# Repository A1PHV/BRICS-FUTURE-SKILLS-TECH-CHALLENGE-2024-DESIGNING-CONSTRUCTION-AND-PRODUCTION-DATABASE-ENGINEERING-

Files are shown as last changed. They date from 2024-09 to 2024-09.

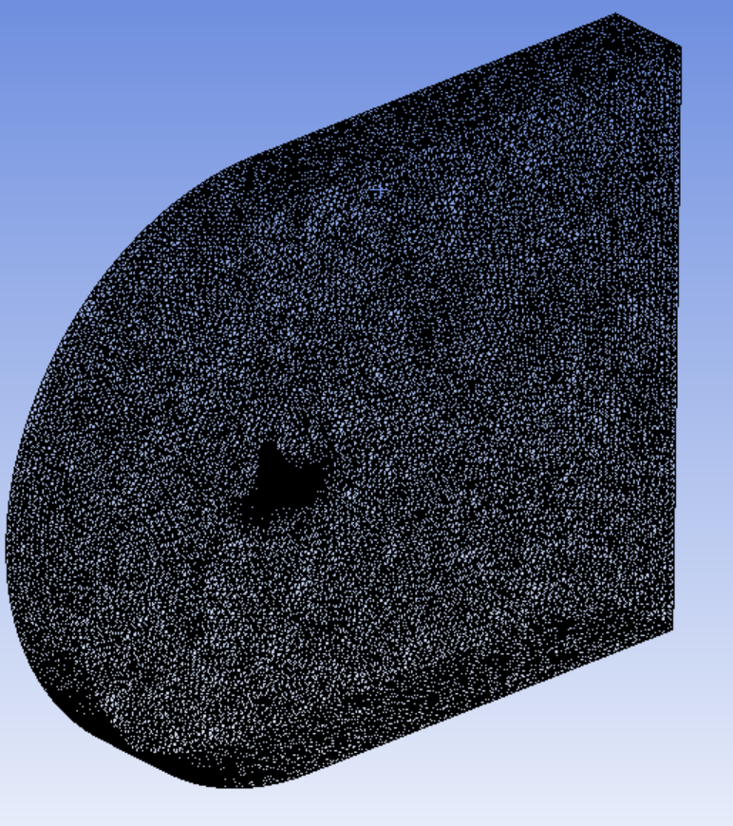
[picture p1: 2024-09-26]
Результаты расчета/Ansys/Сетка.png

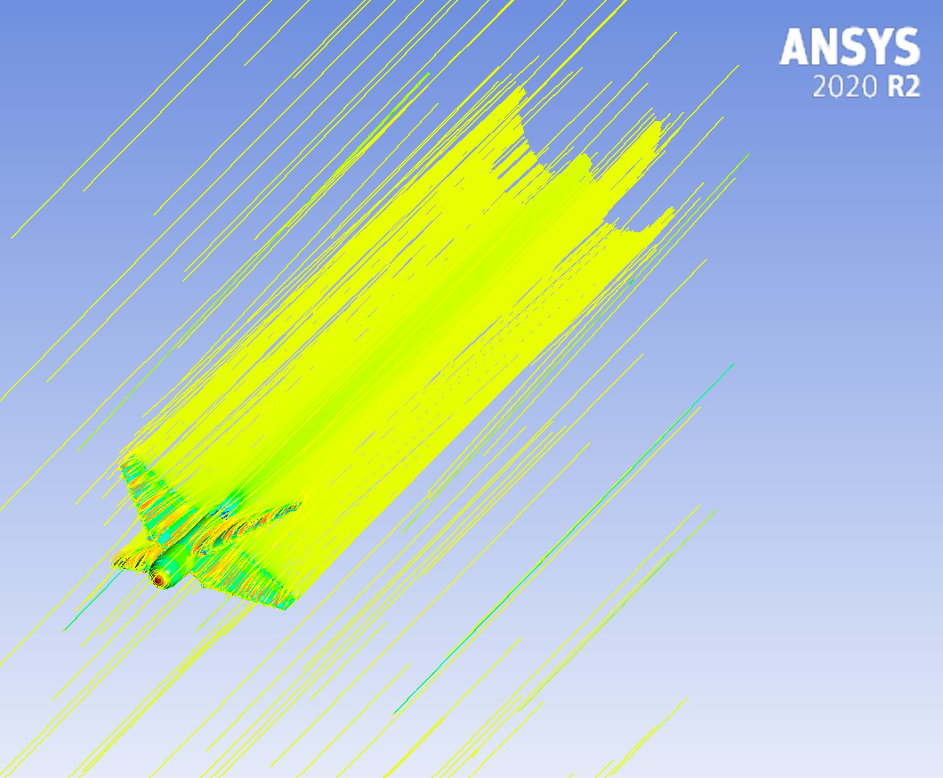
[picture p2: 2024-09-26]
Результаты расчета/Ansys/Альфа_3_1.png

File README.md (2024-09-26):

# BRICS-FUTURE-SKILLS-TECH-CHALLENGE-2024-ПРОЕКТИРОВАНИЕ-КОНСТРУИРОВАНИЕ-И-ПРОИЗВОДСТВЕННАЯ-ИНЖЕНЕРИЯ-БАС
### Название проекта:
  Sagittarius
### Цель:
  Создать проект малого БПЛА для доставки медикаментов в труднодоступные и отдалённые места.
### Основные функции и преимущества системы: 
  - Оперативная доставка необходимого оборудования и материалов к месту чрезвычайной ситуации (до 30 минут)
  - Возможность оснащения различной целевой нагрузкой в зависимости от задачи
  - Низкая стоимость изготовления, сборки, обслуживания
  - Простота обслуживания и применения
  - Снижение углеродного следа и повышенная экологичность
  - Возможность применения в местности с отсутствием инфраструктуры 
  - Ниша с малой конкуренцией на рынке БПЛА
  - Высокий уровень автоматизации системы 
### Описание:
  Беспилотные летательные аппараты (БПЛА) становятся всё более популярными благодаря простоте их изготовления, лёгкости в обслуживании и способности к оперативной доставке оборудования в труднодоступные зоны за считанные минуты. Они значительно уменьшают воздействие на ресурсы планеты, потребляя меньше топлива, что делает их более экологически чистым решением в сравнении с классическими ЛА. БПЛА особенно полезны в труднодоступных местах, где отсутствует инфраструктура. Небольшая конкурентность на рынке предоставляет возможности для новых компаний и инновационных решений. Гибкость в конфигурации целевой нагрузки позволяет использовать БПЛА для различных задач, включая доставку медикаментов, мониторинг экологии, исследование местности и множество других задач. Эти преимущества превращают БПЛА в универсальные инструменты, способные эффективно реагировать на современные вызовы. Основная задача, которую решает наш проект, это проблема доставки медикаментов в труднодоступные места, где отсутствует явная инфраструктура, за кратчайшие сроки.
| ФИО Участника | Роль | Обязанности |
|---|---|---|
| Макаров Леонид Алексеевич | Капитан | Выстраивание рабочего процесса в команде, контроль выполнения задач |
| Лукьянова София Дмитриевна | Конструктор | Моделирование изготавливаемой модели, составление чертежей |
| Ефремов Александр Владимирович | Технолог | Разработка процесса производства, сборки и эксплуатации изделия |
| Жеков Александр Романович | Проектировщик  | Выбор аэродинамической компоновки, расчет проекта |
| Коротков Сергей Сергеевич | Программист | Модернизация программного обеспечения |
### Таблица:
[Таблица](https://docs.google.com/spreadsheets/d/11EvWEyuFIVLWnHRkrs40eNkXgBEI7as9F1RAO528Gh0/edit?gid=0#gid=0)
### Требования к системе:
  - Обеспечить доставку грузов в радиусе 15 км;
  - Обеспечить потребного времени полета (30 мин.);
  - Обеспечить эксплуатацию на площадках с минимальной подготовкой;
  - Обеспечить доставку груза (приземления) на неподготовленные площадки;
  - Обеспечить эксплуатацию оператором с минимальным образованием;
  - Автономный полет.

## Проектирование
Результаты расчетов и 3д модель в различных форматах приложены в репозитории.
Фото летных испытаний можно найти в репозитории, а также по [ссылке на яндекс диске](https://disk.yandex.ru/d/UMUnpoecSOcVCQ).

## Итоговый отчёт представлен в различных форматах в корневой папке.

## Презентация
Доступна [по ссылке на ЯД](https://disk.yandex.ru/d/4SBGewQKKxqp1A) из-за большого объема.

# BRICS-FUTURE-SKILLS-TECH-CHALLENGE-2024-DESIGNING-CONSTRUCTION-AND-PRODUCTION-DATABASE-ENGINEERING
### Project name:
  Sagittarius
### Goal:
  To create a small UAV project for delivering medical supplies to hard-to-reach and remote areas.
  
### Key features and system advantages:
  - Rapid delivery of essential equipment and materials to emergency locations (within 30 minutes)
  - Ability to equip with various payloads depending on the task
  - Low cost of production, assembly, and maintenance
  - Easy to maintain and operate
  - Reduced carbon footprint and increased eco-friendliness
  - Usable in areas with no infrastructure
  - Low competition niche in the UAV market
  - High level of system automation
  
### Description:
  Unmanned aerial vehicles (UAVs) are becoming increasingly popular due to their ease of manufacturing, low maintenance, and ability to quickly deliver equipment to remote locations within minutes. They significantly reduce the strain on planetary resources, consuming less fuel, which makes them a more environmentally friendly solution compared to traditional aircraft. UAVs are especially useful in remote areas where infrastructure is lacking. Low competition in the market offers opportunities for new companies and innovative solutions. The flexibility in configuring the payload allows UAVs to be used for various tasks, including medical deliveries, environmental monitoring, terrain exploration, and many other applications. These advantages make UAVs versatile tools capable of effectively responding to modern challenges. The main task our project addresses is the problem of delivering medical supplies to remote areas lacking clear infrastructure in the shortest possible time.
| Participant's Name | Role | Responsibilities |
|---|---|---|
| Makarov Leonid Alekseevich | Captain | Organizing the team’s workflow, monitoring task completion |
| Lukyanova Sofia Dmitrievna | Constructor | Modeling the product, drafting the technical drawings |
| Efremov Alexander Vladimirovich | Technologist | Developing the production process, assembly, and product operation |
| Zhekov Alexander Romanovich | Designer | Selecting the aerodynamic configuration, project calculations |
| Korotkov Sergey Sergeevich | Programmer | Software modernization |
### Table:
[Тable](https://docs.google.com/spreadsheets/d/11EvWEyuFIVLWnHRkrs40eNkXgBEI7as9F1RAO528Gh0/edit?gid=0#gid=0)
### System requirements:
  - Ensure the delivery of goods within a radius of 15 km;
  - To ensure the required flight time (30 minutes);
  - To ensure operation on sites with minimal preparation;
  - To ensure the delivery of cargo (landing) to unprepared sites;
  - Ensure operation by an operator with minimal education;
  - Autonomous flight.

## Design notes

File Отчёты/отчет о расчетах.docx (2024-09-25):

Описание этапов проектирования

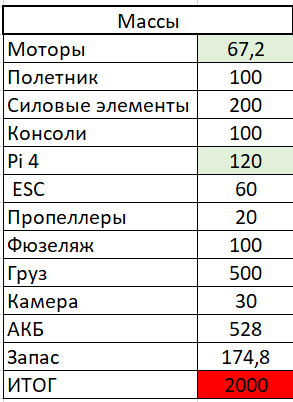
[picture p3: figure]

1. Анализ рынка
2. Создание весовой сводки

Исходя из представленных требований и наборы необходимых компонентов масса ЛА была выбрана 2кг, далее составлена весовая сводка по агрегатам и элементам.

3. Расчет винто-моторной группы

Для того, чтобы иметь точное представление о том, какой нужен аккумулятор и двигатель, проведём несколько расчётов. Первым делом выведем формулу, с помощью которой сможем посчитать ёмкость АКБ для маршевого и подъёмных двигателей.

E=P/U⋅1/η⋅t⋅(1+Q)⋅ke⋅kc

Где: E – ёмкость АКБ в Ампер*час;

P – крейсерская мощность двигателя(ей) в Ваттах;

U – напряжение АКБ в Вольтах;

η – КПД мотора(ов);

t – время полёта в Часах;

Q – аэронавигационный запас;

ke – коэффициент, учитывающий просадку напряжения при малой остаточной емкости;

kc – коэффициент, учитывающий зависимость располагаемой емкости от скорости разряда.

Итог расчета:

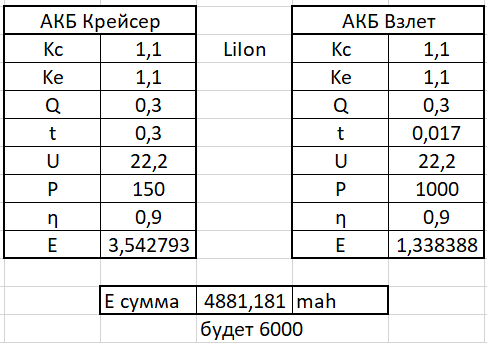
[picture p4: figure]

4. Расчет проектных параметров

Крейсерская скорость бралась исходя из анализа дальности и потребления двигателя.

- Взлетная масса - 2 кг;
- Крейсерская скорость - 108 км/ч (30 м/c);
- Плотность воздуха на высоте 100м - 1,213 кг/м3;

Расчет скоростного напора

В исходных данных мы имеем все необходимые значения для расчета скоростного напора по формуле:

Получено значение q=546 [кг/(м*с)^2].

Удельная нагрузка на крыло

Су крейс. = 0,4 – коэффициент подъемной силы, взятый из программы OpenVSP для модели аппарата в нулевом приближении;

Удельную нагрузку было решено взять исходя из опыта в проектировании малых ЛА. Получено значение p``=65 [кгс/м^2];

Размеры крыла

Имея удельную нагрузку на крыло, можем вычислить потребную площадь крыла по формуле:

(1)

Где:

m0 – масса в первом приближении [кг];

p``0 – удельная нагрузка на крыло. Получаем S=0,307 [м^2];

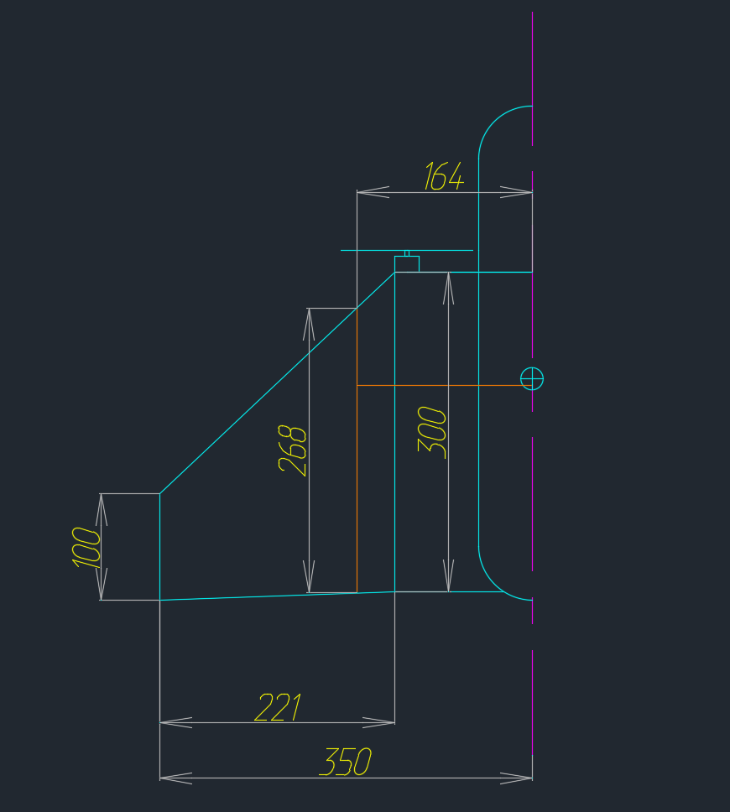
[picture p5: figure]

5. Расчет геометрических параметров

Геометрические параметры ЛА в программе AutoCad

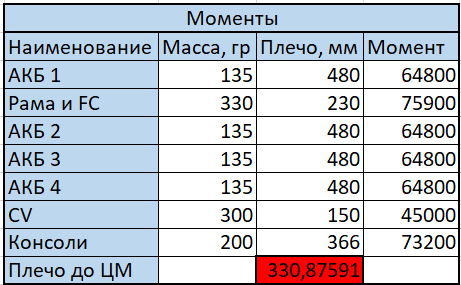
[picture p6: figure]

6. Создание центровочной ведомости

Центровочная ведомость

7. Анализ аэродинамических параметров

Перед тем как выбрать профиль крыла, необходимо оценить параметры среды на заданном режиме полета – расчет числа Рейнольдса на крейсерской скорости:

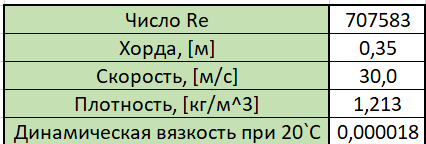
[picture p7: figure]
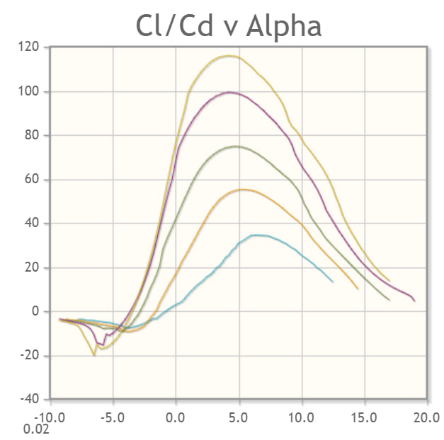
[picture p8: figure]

В качестве аэродинамического профиля крыла выбран профиль sd7037-il так как он хорошо оптимизирован под эксплуатационный диапазон чисел Рейнольдса нашего ЛА. Характеристики профиля были оценены в специализированной программе XFLR5 и получены следующие зависимости

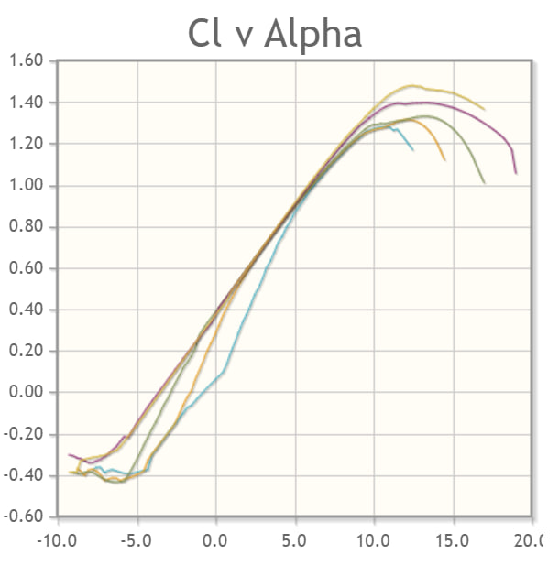
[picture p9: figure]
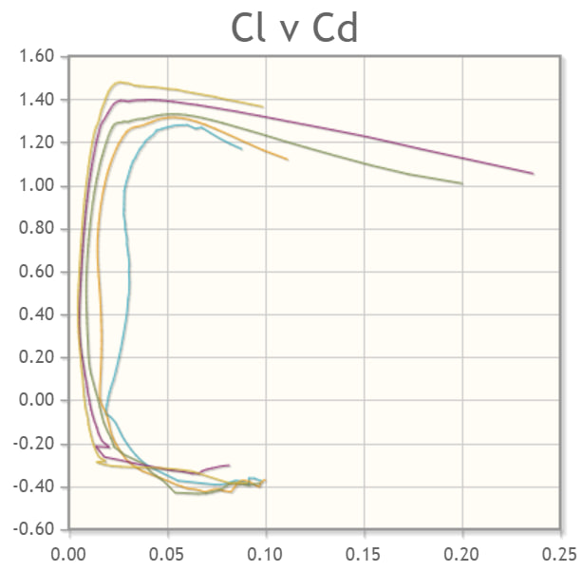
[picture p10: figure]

На графиках представлены зависимости аэродинамического качества от угла атаки, коэффициента подъемной силы от угла атаки и коэффициената подъемной силы от коэффициента лобового сопротивления соответственно.

Далее представлена расчетная модель крыла изделия в XFLR5.

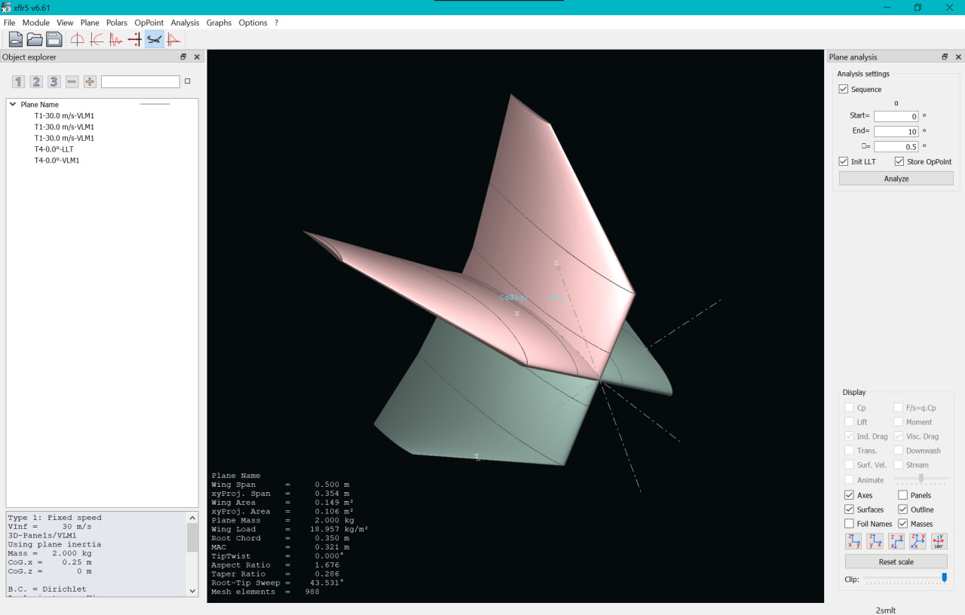
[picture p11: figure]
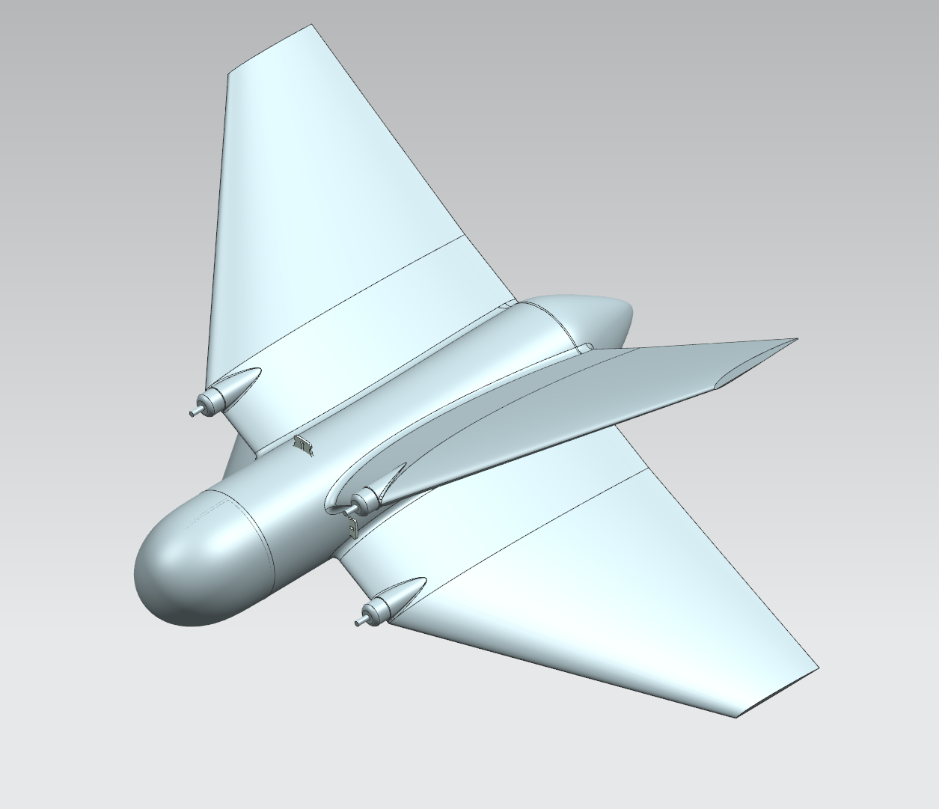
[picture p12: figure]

8. Создание электронного макета изделия

Электронный макет ЛА, созданый в программе Siemens NX.

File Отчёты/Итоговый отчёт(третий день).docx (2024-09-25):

Содержание:

# Оглавление

# 1. Перечень сокращений и терминов

- АК – авиационный комплекс;
- НПУ – наземный пункт управления;
- ЛА – летательный аппарат;
- БПЛА – беспилотный ЛА;

# 2. Описание проекта

## Цель проекта

Цель проекта заключается в разработке компактного беспилотного летательного аппарата, способного эффективно доставлять медикаменты в труднодоступные и отдаленные регионы. Данный БПЛА позволит значительно сократить время доставки жизненно важных лекарств в экстренных ситуациях и в условиях ограниченного доступа. Кроме того, проект направлен на улучшение доступности медицинских услуг для жителей удаленных территорий, обеспечивая их необходимыми препаратами и материалами.

## Преимущества БПЛА

Беспилотные летательные аппараты (БПЛА) становятся всё более популярными благодаря своим многочисленным преимуществам, которые делают их незаменимыми в различных сферах деятельности. Одним из самых значимых плюсов является лёгкость в обслуживании. Современные БПЛА разработаны с учётом простоты эксплуатации, что позволяет сократить время на обучение операторов и минимизировать затраты на техническое обслуживание. Кроме того, использование БПЛА способствует уменьшению воздействия на ресурсы планеты. Они потребляют значительно меньше топлива по сравнению с традиционными транспортными средствами, что делает их экологически чистым решением.

Одной из ключевых функций БПЛА является их способность к оперативной доставке необходимого оборудования в зоны чрезвычайных ситуаций, что крайне важно в случаях, когда каждая секунда на счету.

В настоящее время рынок БПЛА обладает небольшой конкурентностью, что предоставляет возможности для новых игроков и инновационных решений. Это создает простор для творческого подхода и внедрения оригинальных технологий.

Также, БПЛА предлагают возможность использования различных конфигураций целевой нагрузки, что расширяет их сферу применения. Это может быть как доставка медикаментов и продовольствия, так и мониторинг экологической ситуации или проведение инспекций инфраструктуры. Гибкость в настройках БПЛА обеспечивает их универсальность и возможность адаптации под конкретные задачи.

Таким образом, беспилотные летательные аппараты представляют собой многофункциональное и эффективное решение для сегодняшних вызовов, сочетая лёгкость в обслуживании, низкое воздействие на окружающую среду, быстрое реагирование на чрезвычайные ситуации, а также широкий спектр применения.

# 3. Анализ рынка

## Сравнение методов грузоперевозки

Грузоперевозка на различных видах транспорта имеет свои недостатки. Вот несколько из них:

1. Автомобильный транспорт:

- Зависимость от дорожной инфраструктуры: Качество дорог и наличие пробок могут значительно увеличить время доставки.

- Необходимость в дозаправки во время пути.

- Высокий уровень выбросов CO2 и загрязнение окружающей среды.

2. Железнодорожный транспорт:

- Неподвижность маршрутов: Поезда следуют строго определенным маршрутам, что может ограничить гибкость доставки и потребовать дополнительных затрат на подвозку грузов к станции.

- Ограниченная скорость: Средняя скорость 10 км/ч, также процессы погрузки и разгрузки требуют времени.

- Аварийные ситуации: Возможные задержки из-за технических неполадок или серьезных инцидентов на путях.

3. Крупный авиационный транспорт:

- Высокая стоимость: Доставка грузов по воздуху значительно дороже, чем другими видами транспорта, что делает ее менее доступной.

- Зависимость от инфраструктуры: отсутствие взлётно-посадочных полос, ангаров и квалифицированного персонала.

- Чувствительность к погодным условиям: Неблагоприятные погодные условия могут вызывать задержки и отмены рейсов.

4. Речной транспорт:

- Долгое время доставки: Перевозка грузов занимает много времени, что может быть критично для срочных грузов.

- Зависимость от портовой инфраструктуры: Задержки в портах из-за плохих погодных условий или перегрузки могут значительно увеличить общее время доставки.

- Риски повреждения грузов: Грузы могут подвергаться воздействию влаги, соли и других факторов, что может приводить к их повреждению.

Таблица 1 -  Сравнение методов перевозок.

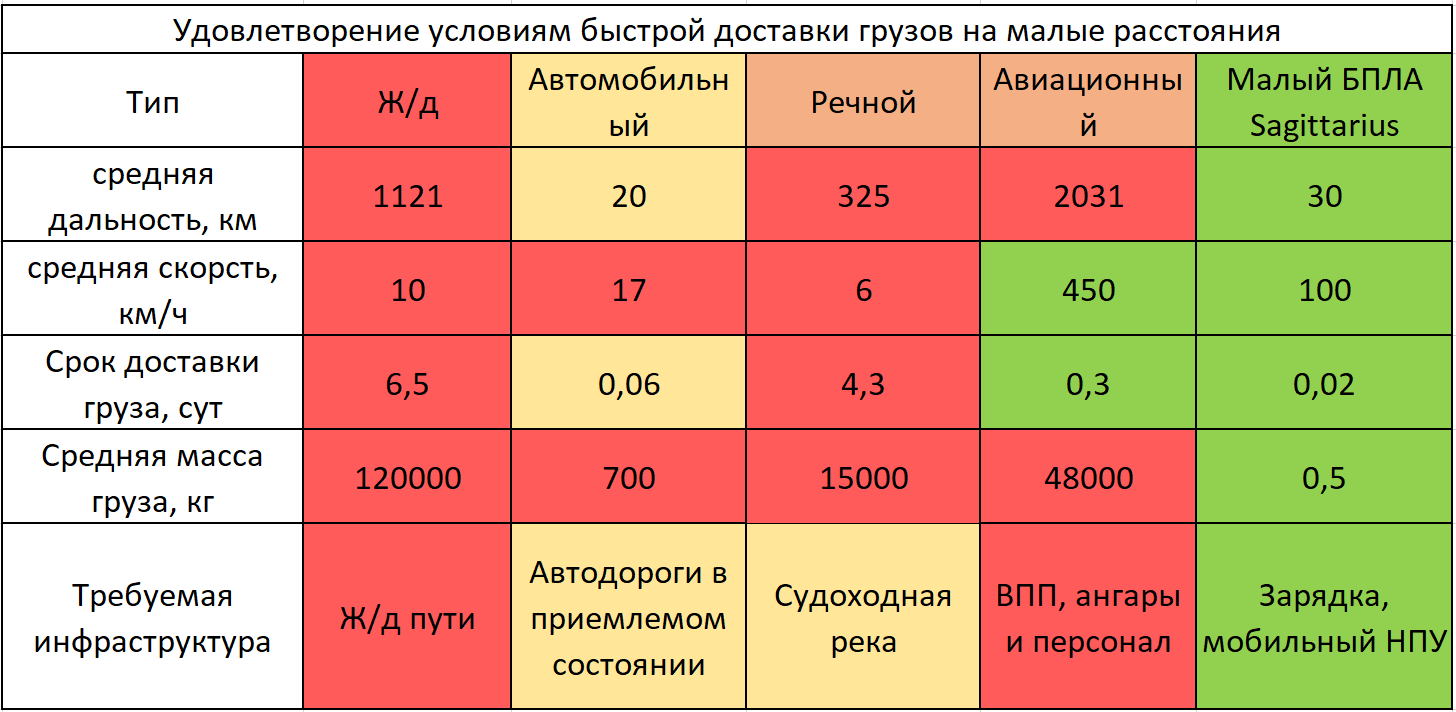
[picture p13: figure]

В настоящее время при доставки малогабаритных и срочных грузов, мы сталкиваемся с такими основными проблемами как, скорость доставки или нецелесообразность запуска крупного транспорта.

## Сравнение прототипов

Таблица 2 -  Сравнение прототипов.

Проанализировав рынок, мы пришли к выводу, что существующие авиационные прототипы нецелесообразно отправлять на небольшие расстояния для доставки медикаментов экстренной помощи. Обслуживание крупного авиационного транспорта является очень дорогим, а также в отдаленных регионах тяжело осуществить посадку, по причине малоразвитой инфраструктуры. В связи с этим нами было принято решение разработать БПЛА с дальностью полёта 30 км, крейсерской скоростью до 100 км/ч и возможностью вертикального взлета и посадки. Наш проект не только заполнит имеющийся рыночный пробел, но и сделает значительный вклад в развитие здравоохранения и экстренной помощи в удаленных регионах.

# 4. Список требований к системе

Требования к системе:

1. Дальность доставки: БПЛА должен иметь возможность совершать полеты на расстоянии до 15 км от стартовой площадки.
2. Время полета: БПЛА должен быть способен поддерживать полет не менее 30 минут, чтобы обеспечить выполнение задачи по доставке груза с учетом потенциальных задержек, отклонений от маршрута и времени на маневрирование при посадке.
3. Подготовка площадок: Обеспечение обслуживание на площадках с минимальной подготовкой.
4. Приземление на неподготовленных площадках: Обеспечение доставки груза (приземления) на неподготовленные площадки. Возможность точно и безопасно приземляться на поверхности с различными типами покрытия (травяные, земляные, бетонные и т.д.), что требует наличия системы автоматического управления и стабилизации во время приземления.
5. Обеспечение эксплуатации оператором с минимальным образованием: Система управления БПЛА должна быть интуитивно понятной, с простым интерфейсом и минимальными требованиями к обучению. Оператор должен иметь возможность быстро освоить управление БПЛА, возможно, с помощью инструкций на экране и простых команд.
6. Автономный полет: БПЛА должен быть оснащен системой автопилота, позволяющей ему совершать полет без непосредственного управления со стороны оператора. Это включает в себя заранее загруженные маршруты, возможность изменения маршрута в режиме реального времени и возможность возврата на базу в случае возникновения непредвиденных обстоятельств (например, разряд батареи, потеря сигнала).

Эти требования помогут обеспечить эффективную и безопасную эксплуатацию системы малого БПЛА для доставки грузов в различных условиях.

# 5. Расчеты ЛА

## Расчет массовых характеристик

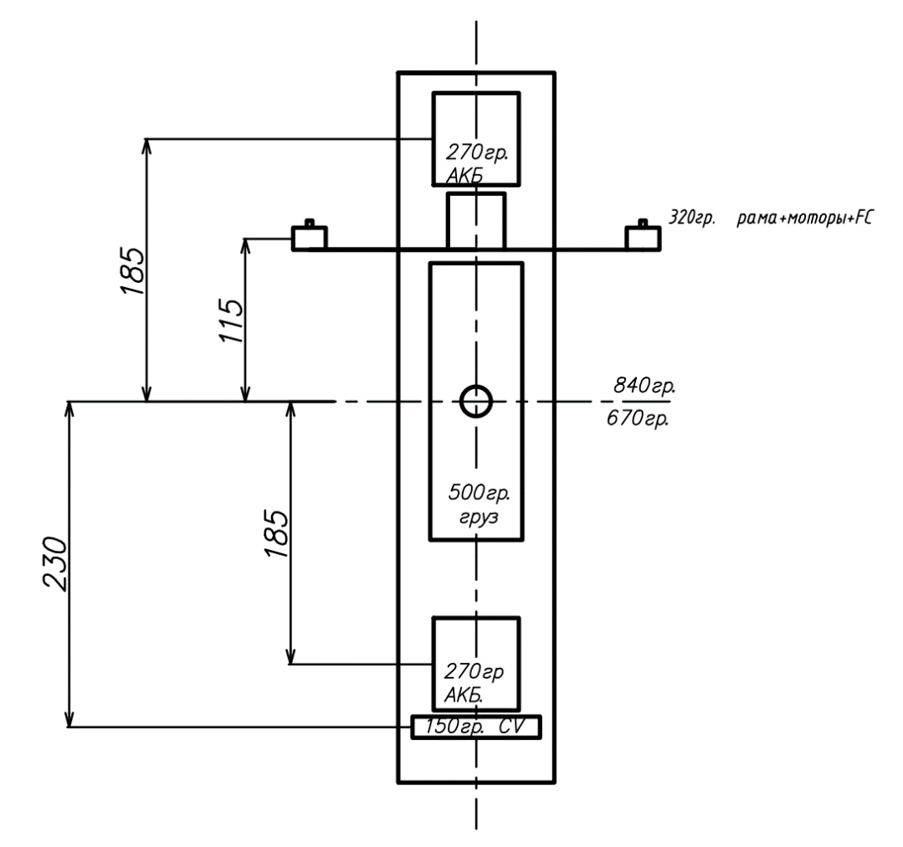
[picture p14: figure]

Рис. 1. -  Центровочная схема.

## Расчеты проектных параметров

## Расчет геометрических характеристик ЛА

## Расчет аэродинамических характеристик ЛА

## Расчет ВМГ

# 6. Построение электронного макета

# 7. Изготовление технологической оснастки

# 8. Описание АК

## Состав АК и причастных людей

В состав авиационного комплекса Sagittarius:

- Оператор

Выполняет обсуживание и загрузку полезной нагрузки в БПЛА на базе, настраивает и запускает миссию на доставку, а также контролирует ход её выполнения, имеет связь с каналом экстренных служб для получения информации о необходимости доставки.

- НПУ

Обеспечивает связь между оператором и роем БПЛА, управление роем.

- БПЛА (предполагается размещение нескольких единиц на одной базе)

Заряжается от НПУ, груз загружается вручную оператором, получает миссию от НПУ и автономно летит в точку назначения.

С АК взаимодействуют:

- Оператор экстренных служб (ОЭС) – передает данные о необходимости доставки, состав запрапрашиваемой доставки и точку назначения;
- Получатель – пострадавший или иной человек, кому потребовалась срочная доставка посылки от экстренных служб. Сообщает ОЭС свое местоположение и описывает ситуацию, извлекает груз из БПЛА в точке приземления.

## Взаимодействие элементов АК

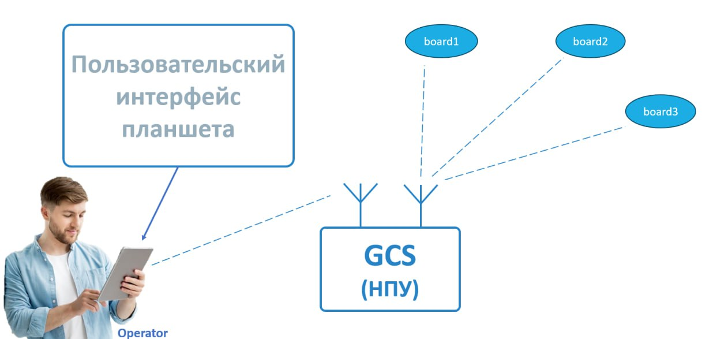
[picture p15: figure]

Рис. 2. -  Схема работы оператора

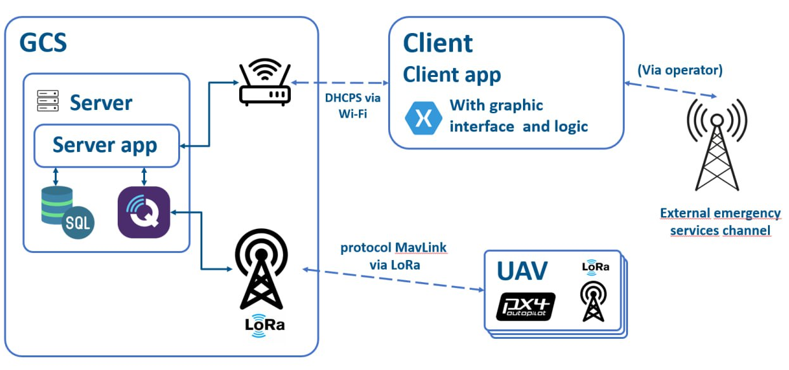
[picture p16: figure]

Рис. 3. -  Схема архитектуры взаимодействия

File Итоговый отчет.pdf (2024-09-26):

ОКБ СУХОГО
БПЛА Sagittarius

### Оглавление

2

### 7.1. Общий вид изделия | 20

### 7.2. Эксплуатационное членение | 23

### 8. Технологическая документация | 25

### 8.1. Технология изготовления БПЛА | 25

### 8.2. Описание технологического процесса сборки | 26

### 9. Расчёт экономической модели проекта | 1

3

### 1. Перечень сокращений и терминов

- АК – авиационный комплекс;
- НПУ – наземный пункт управления;
- ЛА – летательный аппарат;
- БПЛА – беспилотный ЛА;
- АДХ – Аэродинамические характеристики
- ОЭС

4

### 2. Описание проекта

### 2.1. Цель проекта

Цель проекта заключается в разработке компактного беспилотного летательного аппарата, способного эффективно доставлять медикаменты в труднодоступные и отдаленные регионы. Данный БПЛА позволит значительно сократить время доставки жизненно важных лекарств в экстренных ситуациях и в условиях ограниченного доступа. Кроме того, проект направлен на улучшение доступности медицинских услуг для жителей удаленных территорий, обеспечивая их необходимыми препаратами и материалами.

### 2.2. Преимущества БПЛА

Беспилотные летательные аппараты (БПЛА) становятся всё более популярными благодаря своим многочисленным преимуществам, которые делают их незаменимыми в различных сферах деятельности. Одним из самых значимых плюсов является лёгкость в обслуживании. Современные БПЛА разработаны с учётом простоты эксплуатации, что позволяет сократить время на обучение операторов и минимизировать затраты на техническое обслуживание. Кроме того, использование БПЛА способствует уменьшению воздействия на ресурсы планеты. Они потребляют значительно меньше топлива по сравнению с традиционными транспортными средствами, что делает их экологически чистым решением.
Одной из ключевых функций БПЛА является их способность к оперативной доставке необходимого оборудования в зоны чрезвычайных ситуаций, что крайне важно в случаях, когда каждая секунда на счету.
В настоящее время рынок БПЛА обладает небольшой конкурентностью, что предоставляет возможности для новых игроков и инновационных

5

решений. Это создает простор для творческого подхода и внедрения оригинальных технологий.
Также, БПЛА предлагают возможность использования различных конфигураций целевой нагрузки, что расширяет их сферу применения. Это может быть, как доставка медикаментов и продовольствия, так и мониторинг экологической ситуации или проведение инспекций инфраструктуры. Гибкость в настройках БПЛА обеспечивает их универсальность и возможность адаптации под конкретные задачи.
Таким образом, беспилотные летательные аппараты представляют собой многофункциональное и эффективное решение для сегодняшних вызовов, сочетая лёгкость в обслуживании, низкое воздействие на окружающую среду, быстрое реагирование на чрезвычайные ситуации, а также широкий спектр применения.

6

### 3. Анализ рынка

### 3.1. Сравнение методов грузоперевозки

Грузоперевозка на различных видах транспорта имеет свои недостатки. Вот несколько из них:

### 1. Автомобильный транспорт:

- Зависимость от дорожной инфраструктуры: Качество дорог и наличие пробок могут значительно увеличить время доставки.
- Необходимость в дозаправки во время пути.
- Высокий уровень выбросов CO2 и загрязнение окружающей среды.

### 2. Железнодорожный транспорт:

- Неподвижность маршрутов: Поезда следуют строго определенным маршрутам, что может ограничить гибкость доставки и потребовать дополнительных затрат на подвозку грузов к станции.
- Ограниченная скорость: Средняя скорость 10 км/ч, также процессы погрузки и разгрузки требуют времени.
- Аварийные ситуации: Возможные задержки из-за технических неполадок или серьезных инцидентов на путях.

### 3. Крупный авиационный транспорт:

- Высокая стоимость: Доставка грузов по воздуху значительно дороже, чем другими видами транспорта, что делает ее менее доступной.
- Зависимость от инфраструктуры: отсутствие взлётно-посадочных полос, ангаров и квалифицированного персонала.
- Чувствительность к погодным условиям: Неблагоприятные погодные условия могут вызывать задержки и отмены рейсов.

### 4. Речной транспорт:

- Долгое время доставки: Перевозка грузов занимает много времени, что может быть критично для срочных грузов.

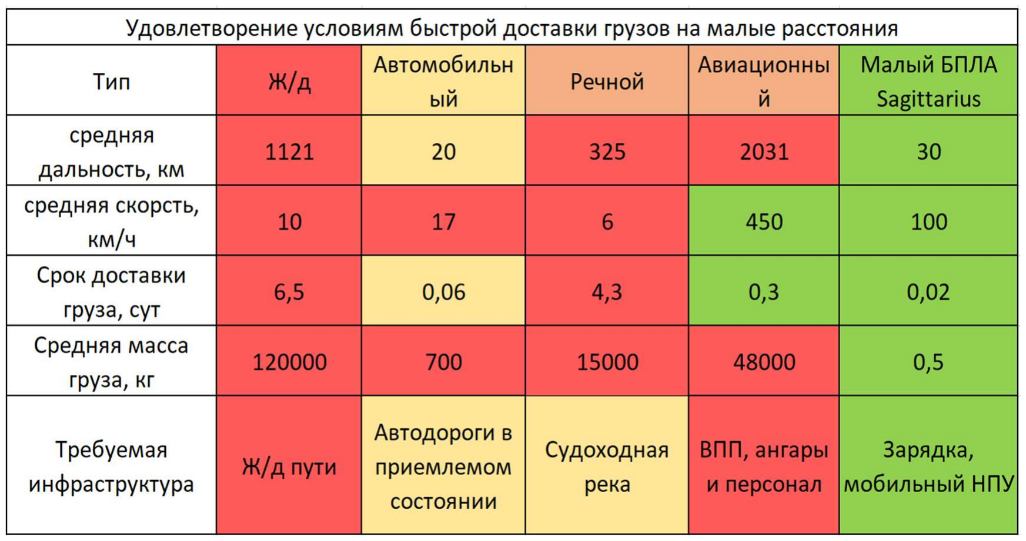
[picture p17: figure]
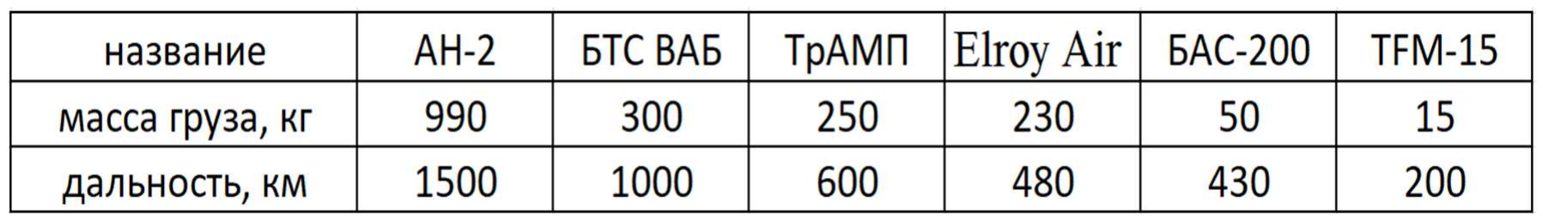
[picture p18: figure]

7

- Зависимость от портовой инфраструктуры: Задержки в портах из-за плохих погодных условий или перегрузки могут значительно увеличить общее время доставки.
- Риски повреждения грузов: Грузы могут подвергаться воздействию влаги, соли и других факторов, что может приводить к их повреждению. Таблица 1 - Сравнение методов перевозок.

В настоящее время при доставки малогабаритных и срочных грузов, мы сталкиваемся с такими основными проблемами как, скорость доставки или нецелесообразность запуска крупного транспорта.

### 3.2. Сравнение прототипов

Таблица 2 - Сравнение прототипов.

8

Проанализировав рынок, мы пришли к выводу, что существующие авиационные прототипы нецелесообразно отправлять на небольшие расстояния для доставки медикаментов экстренной помощи. Обслуживание крупного авиационного транспорта является очень дорогим, а также в отдаленных регионах тяжело осуществить посадку, по причине малоразвитой инфраструктуры. В связи с этим нами было принято решение разработать БПЛА с дальностью полёта 30 км, крейсерской скоростью до 100 км/ч и возможностью вертикального взлета и посадки. Наш проект не только заполнит имеющийся рыночный пробел, но и сделает значительный вклад в развитие здравоохранения и экстренной помощи в удаленных регионах.

0

200

400

600

800

1000

1200

1400

1600

1800

0 | 200 | 400 | 600 | 800 | 1000 | 1200 Дальность полета, км

Масса груза, кг

Зависимость массы груза от дальности полета

9

### 4. Список требований к системе

### 1. Дальность доставки: БПЛА должен иметь возможность совершать

полеты на расстоянии до 15 км от стартовой площадки.

### 2. Время полета: БПЛА должен быть способен поддерживать полет не

менее 30 минут, чтобы обеспечить выполнение задачи по доставке груза с учетом потенциальных задержек, отклонений от маршрута и времени на маневрирование при посадке.

### 3. Подготовка площадок: Обеспечение обслуживания на площадках с

минимальной подготовкой.

### 4. Посадка на неподготовленные площадки: Обеспечение доставки

груза (приземления) на неподготовленные площадки. Возможность точно и безопасно осуществлять посадку на поверхности с различными типами покрытия (травяные, земляные, бетонные и т.д.).
5. Обеспечение | эксплуатации | оператором | с | минимальным
образованием: Система управления БПЛА должна быть интуитивно понятной, с простым интерфейсом и минимальными требованиями к обучению. Оператор должен иметь возможность быстро освоить управление БПЛА.

### 6. Автономный полет: БПЛА должен быть оснащен системой

автопилота, | позволяющей | ему | совершать | полет | без
непосредственного управления со стороны оператора. Это включает в себя заранее загруженные маршруты, возможность изменения маршрута в режиме реального времени и возврата на базу в случае возникновения непредвиденных обстоятельств (разряд батареи, потеря сигнала).

Данные требования помогут обеспечить эффективную и безопасную эксплуатацию системы малого БПЛА для доставки грузов в различных условиях.

10

### 5. Описание АК

### 5.1. Состав АК и причастных людей

В состав авиационного комплекса Sagittarius:
- Оператор
Выполняет обсуживание и загрузку полезной нагрузки в БПЛА на базе, настраивает и запускает миссию на доставку, а также контролирует ход её выполнения, имеет связь с каналом экстренных служб для получения информации о необходимости доставки.
- НПУ
Обеспечивает связь между оператором и роем БПЛА, управление роем.
- БПЛА (предполагается размещение нескольких единиц на одной базе) Заряжается от НПУ, груз загружается вручную оператором, получает миссию от НПУ и автономно летит в точку назначения. С АК взаимодействуют:
- Оператор экстренных служб (ОЭС) – передает данные о необходимости доставки, состав запрапрашиваемой доставки и точку назначения;
- Получатель – пострадавший или иной человек, кому потребовалась срочная доставка посылки от экстренных служб. Сообщает ОЭС свое местоположение и описывает ситуацию, извлекает груз из БПЛА в точке приземления.

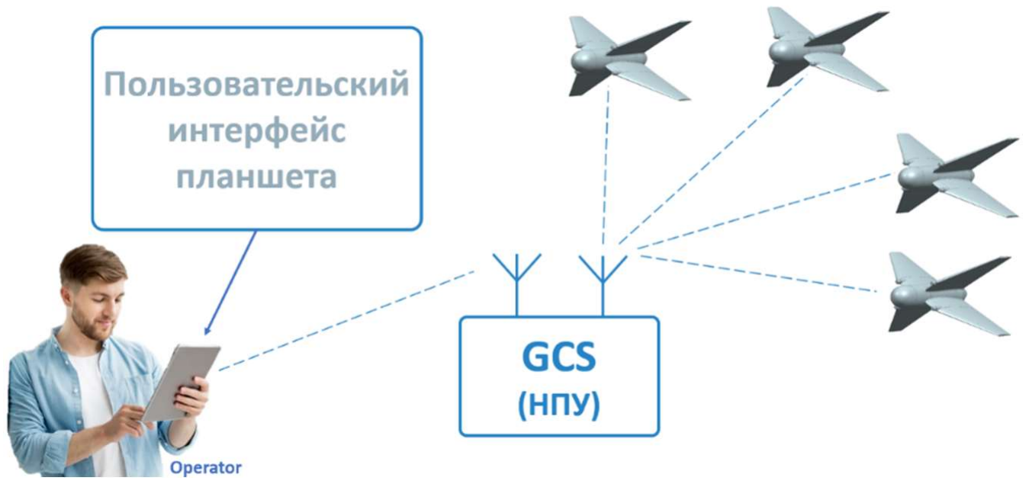
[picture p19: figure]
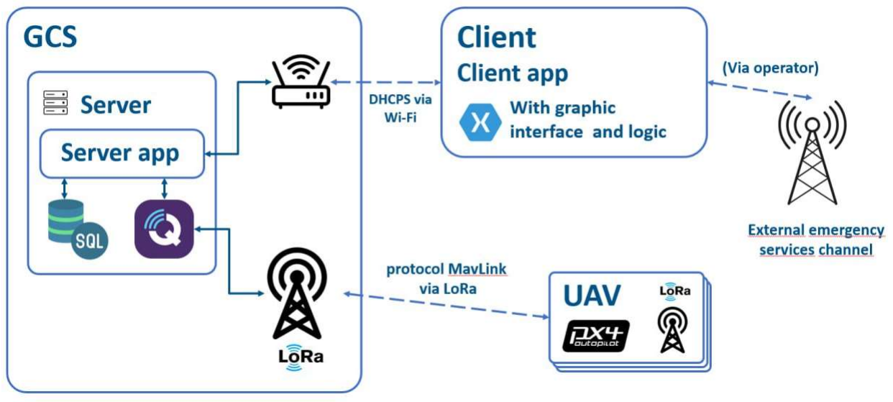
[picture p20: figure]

11

### 5.2. Взаимодействие элементов АК

Рис.11 - Схема работы оператора

Рис.12 - Схема архитектуры взаимодействия Предполагаемый сценарий эксплуатации:
- НПУ расположен на базе экстренных служб;
- На базе присутствует один оператор АК;
- К одной базе присвоены несколько БПЛА;
- Оператор БПЛА получает информацию о необходимости доставки от ОЭС и подготавливает БПЛА к полету, после чего отправляет в полет;
- БПЛА автономно летит до точки назначения и приземляется;
- Заказчик получает свой заказ;
- Дрон автономно возвращается на базу;
- Оператор заряжает БПЛА на базе.
Программная реализация описана и загружена на гит.

12

### 6. Расчеты ЛА

### 6.1. Создание весовой сводки

Таблица 3 - | Весовая сводка в формате Excel
Массы | На макет
Моторы | 67,2 | 67,2
Полетный контроллер | 100 | 50
Силовые элементы | 200 | 200
Консоли | 100 | 250
Pi 4 | 120 | 120
ESC | 60 | 60
Пропеллеры | 20 | 20
Фюзеляж | 100 | 400
Груз | 500 | 500
Камера | 30 | 30
АКБ | 528 | 528
Запас | 174,8 | -
ИТОГ | 2000 | 2225,2
Исходя из представленных требований и набора необходимых компонентов для реализации задачи, масса ЛА была выбрана 2кг, далее составлена весовая сводка по агрегатам и элементам. Также составлена предварительная сводка по массам изготавливаемого демонстратора.

### 6.2. Расчет винто-моторной группы

Для того, чтобы иметь точное представление о том, какой нужен аккумулятор и двигатель, проведём несколько расчётов. Первым делом выведем формулу, с помощью которой сможем посчитать ёмкость АКБ для маршевого и подъёмных двигателей.

E =

P
U

⋅

1
η
| ⋅ t ⋅ (1 + Q) ⋅ ke ⋅ kc

Где: E – ёмкость АКБ в Ампер*час;
P – крейсерская мощность двигателя(ей) в Ваттах; U – напряжение АКБ в Вольтах;

13

η – КПД мотора(ов);
t – время полёта в Часах;
Q – аэронавигационный запас;
ke – коэффициент, учитывающий просадку напряжения при малой остаточной емкости;
kc – коэффициент, учитывающий зависимость располагаемой емкости от скорости разряда.
Таблица 4 - | Итог расчета:
АКБ Крейсер | Тип | АКБ Взлет
Kc | 1,1 | LiIon | Kc | 1,1
Ke | 1,1 | | Ke | 1,1
Q | 0,3 | | Q | 0,3
t | 0,3 | | t | 0,017
U | 22,2 | | U | 22,2
P | 150 | | P | 1000
η | 0,9 | | η | 0,9
E | 3,542793 | | E | 1,338388
E сумма | 4881,181 | mah

### 6.3. Расчет проектных параметров

Крейсерская скорость бралась исходя из анализа дальности и потребления двигателя.
- Взлетная масса - 2 кг;
- Крейсерская скорость - 108 км/ч (30 м/c);
- Плотность воздуха на высоте 100м - 1,213 кг/м3; Расчет скоростного напора

14

В исходных данных мы имеем все необходимые значения для расчета скоростного напора по формуле:

Получено значение q=546 [кг/(м*с)^2].
Удельная нагрузка на крыло
Удельную нагрузку было решено взять исходя из опыта в проектировании малых ЛА. Наиболее оптимальные значения для аппаратов такой размерности лежат в диапазоне от 40 до 75 [г/дм^2]. С целью обеспечения требуемых размеров крыла и необходимой маневренности было задано значение p``=65 [г/дм^2];
Размеры крыла
Имея удельную нагрузку на крыло, можем вычислить потребную площадь крыла по формуле:

Где:
m0 – масса в первом приближении [кг]; p``0 – удельная нагрузка на крыло.
Получаем S=0,307 [м^2];

### 6.4. Расчет геометрических параметров

Геометрические параметры рассчитаны с учетом граничных условий по размаху (< 750мм) и хорде крыла (< 350мм). Для управления в каналах тангажа и крена по время горизонтального полета нами были предусмотрены органы управления – элевоны. Для создания необходимого момента их площадь была рассчитана 0.1Sкр (стандартное соотношение для малой авиации). Оперируя потребной площадью крыла и граничными условиями мы составили предварительный вид плановой проекции ЛА в программе AutoCad.

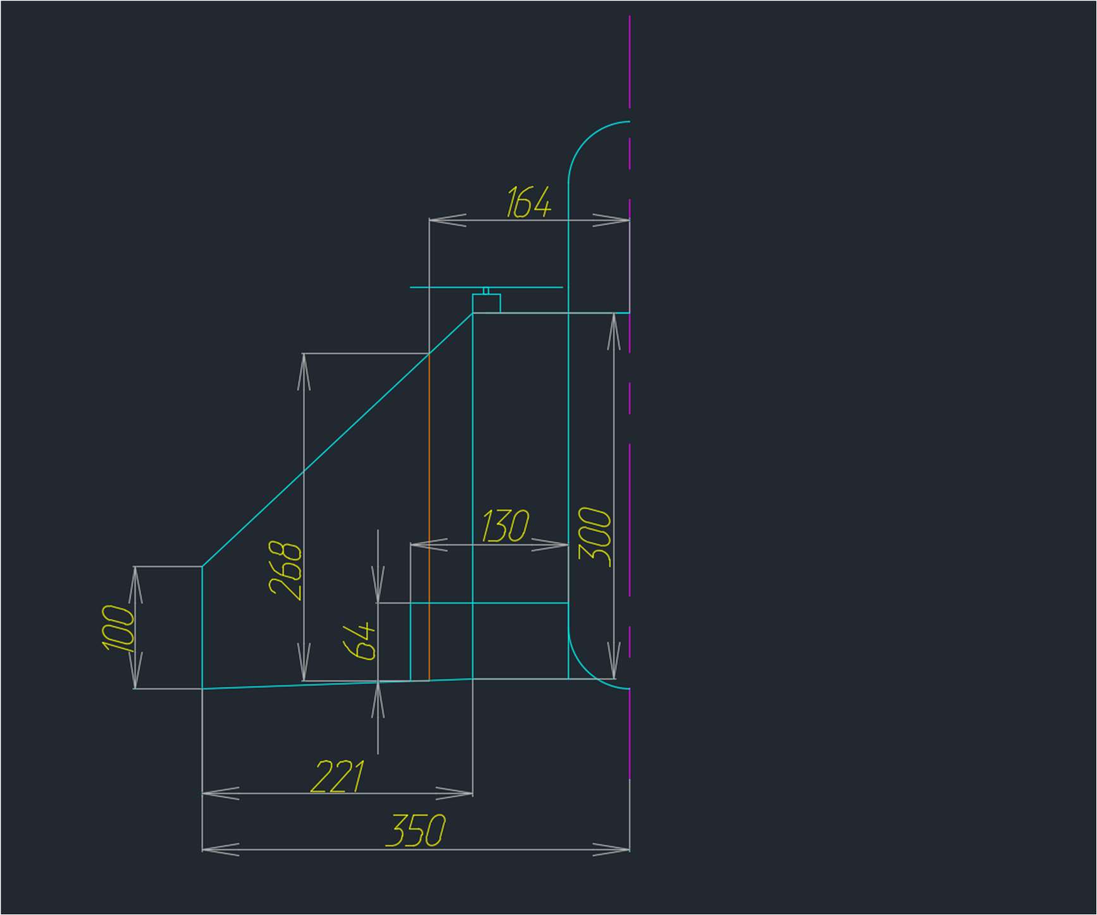
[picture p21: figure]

15

Рис. 1. - Чертеж плановой проекции на одну консоль в программе AutoCad

### 6.5. Создание центровочной ведомости

Обеспечивая устойчивый полет, центр масс самолета должен находится впереди точки приложения подъемной силы. Для определения центра масс нами была составлена центровочная ведомость в программе Excel и схема расположения блоков электроники в программе AutoCad.
Таблица 5 - | Центровочная ведомость в программе Excel
| Моменты
Наименование | Масса, гр | Плечо, мм | Момент
АКБ 1 | 135 | 480 | 64800
Рама и FC | 330 | 230 | 75900
АКБ 2 | 135 | 480 | 64800
АКБ 3 | 135 | 480 | 64800
АКБ 4 | 135 | 480 | 64800
CV | 300 | 150 | 45000
Консоли | 200 | 366 | 73200
Координата ЦМ | | 330,87591

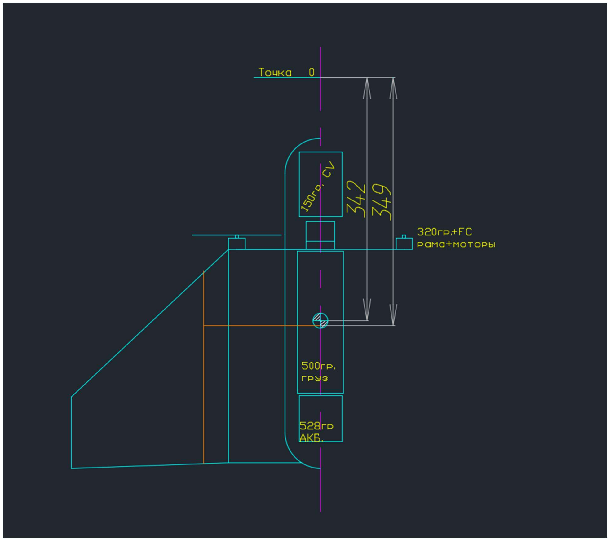
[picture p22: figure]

16

Рис. 2. - Схема центровки в программе AutoCad

### 6.6. Анализ аэродинамических параметров

Перед тем как выбрать профиль крыла, необходимо оценить параметры среды на заданном режиме полета – расчет числа Рейнольдса на крейсерской скорости:

Число Re | 707583
Хорда, [м] | 0,35
Скорость, [м/с] | 30,0
Плотность, [кг/м^3] | 1,213
Динамическая вязкость при 20`С | 0,000018

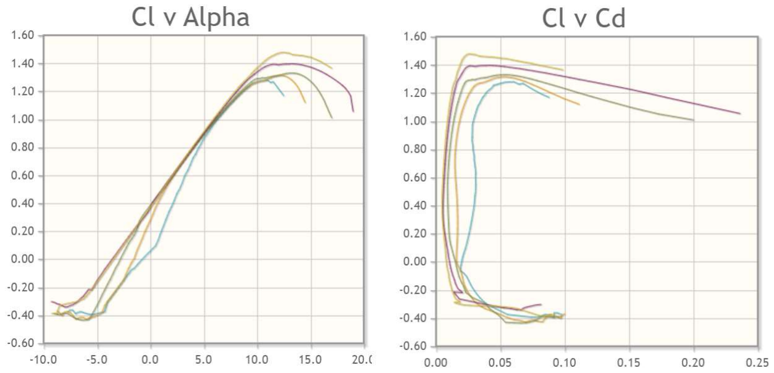
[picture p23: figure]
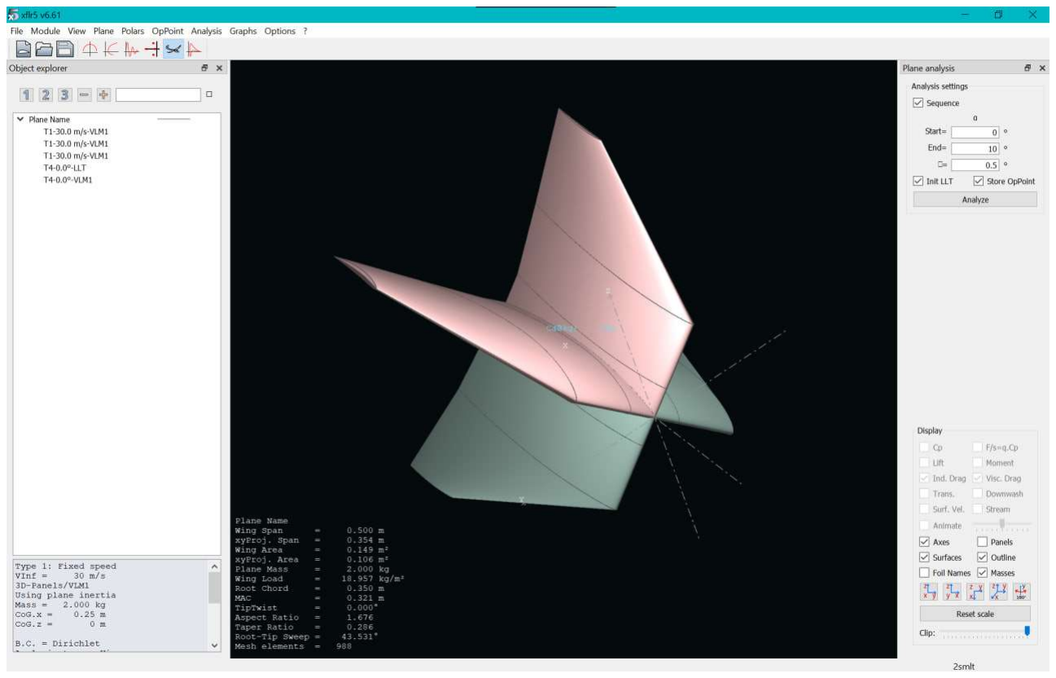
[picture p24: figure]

17

В качестве аэродинамического профиля крыла выбран профиль sd7037-il так как он хорошо оптимизирован под эксплуатационный диапазон чисел Рейнольдса нашего ЛА. Характеристики профиля были оценены в Airfoiltools и получены следующие зависимости:

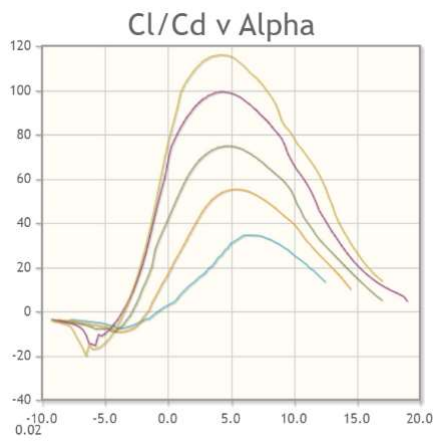
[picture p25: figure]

На графиках представлены зависимости аэродинамического качества от угла атаки, коэффициента подъемной силы от угла атаки и коэффициената подъемной силы от коэффициента лобового сопротивления соответственно. Далее представлена расчетная модель крыла изделия в XFLR5 для более детальной оценки АДХ.

После проведения расчета была обнаружена избыточная курсовая устойчивость и недостаточная площадь крыла в плане, в связи с этим Х-

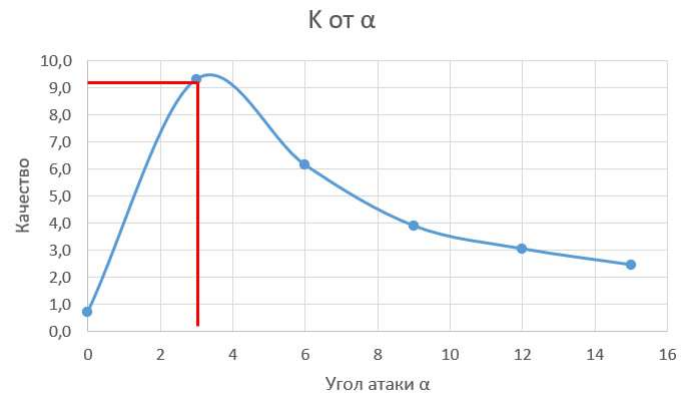
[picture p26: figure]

18

образность была изменена до угла развала консолей 60 градусов от ПСС, увеличен размах крыла и уменьшена корневая хорда.

### 6.7. Расчет аэродинамических характеристик в ANSYS

Для обеспечения устойчивости и управляемости в различных режимах полета необходимо тщательно анализировать характеристики аэродинамического профиля. Расчет аэродинамических характеристик был проведен в программе ANSYS. Дополнительно, были проведены эксперименты с изменением угла атаки для определения оптимальных условий работы аппарата. По результатам рассчёта был выбран крейсерский угол атаки, исходя из условия максимального качества. Максимальное качество нашего аппарата равно 9, и реализовывается на полетном угле атаки, равным 3°

Рис. 3. - Зависимость качества от угла атаки Полученные данные будут использоваться для дальнейшей оптимизации конструкции и повышения эффективности полета.


19

Была построена объемная треугольная сетка, изображение приведено ниже.

Рис. 4. - Сетка в ANSYS
После чего был произведен расчет на различных углах атаки (0, 3, 6, 9, 12, 15), и выявлен оптимальный (по методике, описанной выше) для крейсерского полета.

Рис. 5. - Распределение давления при угле атаки 0 град.


20

### 7. Построение электронного макета

Электронный макет был выполнен в CAD программе Siemens NX.

### 7.1. Общий вид изделия

Рис. 6. - 3д вид модели


21

Рис. 7. - Плановая проекция сверху

Рис. 8. - Боковая проекция сбоку


22

Рис. 9. - Фронтальная проекция

Рис. 10. - КСС БПЛА

### 7.2. Эксплуатационное членение


23

Рис. 11. - | Сегмент фюзеляжа
Рис. 12. - | Фюзеляж, готовый к установке консолей


24

Рис. 13. - БПЛА готовый к использованию


25

### 8. Технологическая документация

### 8.1. Технология изготовления БПЛА

Фюзеляж и консоли изготавливаются из композиционного материала с использованием пуансона. В верхнюю и нижние матрицы закладываются слои карбона, затем укладывается пеноплексовый пуансон и закрывается ответной частью матрицы. Конструкция плотно скручивается и остается до полимеризации смолы.
Обтекатели изготавливаются при помощи аддитивных технологий (3д печать из пластика PET-G)
КСС нарезается из карбоновых листов на фрезерном станке.
Все клеевые соединения производятся на эпоксидную смолу. Резьбовые соединения изготавливаются из стальных заготовок.

Рис. 14. - Резьбовые элементы, изготовляемые из металла

26

### 8.2. Описание технологического процесса сборки

1. БПЛА достается из коробки;
2. В неотъемные части крыла вкручиваются задние лонжероны;
3. На лонжероны надеваются отъёмные части крыла;

### 4. ОЧК фиксируются при помощи винтов в закладные задних

лонжеронов.
Процесс сборки соответствует изображением пункта 6.2 эксплуатационное членение.

### 9. Расчёт экономической модели проекта

Чтобы запустить проект в серийное производство, был произведен расчет экономической составляющей проекта. Оценили стоимость всех расходных материалов, а также определили затраты на необходимое оборудование и дополнительные расходы. Рассчитали амортизацию оборудования, чтобы понять его стоимость в течение срока службы. На основе этих данных мы смогли вычислить себестоимость одного авиационного комплекса, в который входит наземный пункт управления и 5 БПЛА.
Кроме того, мы учли потенциальные риски и конкуренцию на рынке, что поможет в дальнейшем оптимизировать наши расходы и повысить эффективность производства.

Таблица 6 - Экономический расчет


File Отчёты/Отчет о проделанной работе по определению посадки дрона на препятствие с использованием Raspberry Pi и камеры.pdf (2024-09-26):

### Введение

Целью данного решения была разработка системы для автоматического обнаружения того, что дрон сел на дерево или столкнулся с другим препятствием, используя Raspberry Pi и камеру. В ходе работы были использованы методы компьютерного зрения и алгоритмы обработки изображений для идентификации окружающих объектов и корректного реагирования на инциденты.

### Оборудование и ПО

Для выполнения данной задачи использовались следующие компоненты:

### Основная идея

Главная задача системы — обнаружить момент, когда дрон совершил неудачную посадку на дерево или другое препятствие, и инициировать соответствующие действия. Для этого реализован алгоритм, использующий компьютерное зрение, который анализирует данные с камеры в режиме реального времени. При обнаружении потенциального препятствия система реагирует либо уклонением, либо, если избежать препятствия не удается, производит автономную посадку.

### Алгоритм работы

Алгоритм реализован по следующему принципу:

Raspberry Pi 4 с камерой.
OpenCV для обработки изображений.
Python как язык программирования.
ROS (Robot Operating System) для обмена сообщениями и управления дроном.
1. Захват данных с камеры: Камера на борту дрона постоянно передает видеопоток на Raspberry Pi.
2. Обработка изображений:
Видео анализируется в режиме реального времени с использованием OpenCV. Для простоты алгоритма изображение преобразуется в оттенки серого для дальнейшей обработки.
Проводится выделение контуров, а затем применяется метод выделения препятствий для анализа ближайшего окружения.

### Реализация алгоритма

Основная логика алгоритма представлена в виде блок-схемы.

### Блок-схема алгоритма

3. Обнаружение препятствий: Система использует алгоритм обнаружения объектов (в данном случае – деревьев и других препятствий). Для этого был использован алгоритм YOLO. Если обнаруживается объект в опасной близости, запускается сценарий обработки инцидента.
4. Реакция на инцидент:
При обнаружении столкновения с деревом или другим объектом система посылает сигнал для изменения курса или запуска алгоритма безопасной посадки.
5. Безопасная посадка:
Если столкновение неизбежно, система предпринимает действия по безопасной посадке дрона. Это может включать снижение скорости, анализ ближайших объектов и выбор наиболее безопасного места для приземления.

+----------------------------+

| Запуск системы | |

+----------------------------+

v

+----------------------------+

| Захват данных с камеры | |

+----------------------------+

v

+----------------------------+

| Обработка изображения | |
| (преобразование в оттенки | |
| | серого, фильтрация) | |

+----------------------------+
| v

+----------------------------+

| Обнаружение препятствий | |

+--------------------+ +-------------------+
| Столкновение | | Продолжение |
| обнаружено? | | полета |
+--------------------+ +-------------------+ |
v
+-------------------------+
| Сигнал о столкновении |
| и запуск алгоритма |
| реагирования |
+-------------------------+
v
+-----------------------------+ | Автономная посадка/ |
| изменение курса |
+-----------------------------+

### Код реализации на Python с использованием OpenCV

import cv2

cap = cv2.VideoCapture(0)

while True:

# Чтение кадра

ret, frame = cap.read()

if not ret:

break

| (алгоритм YOLO) | |

+----------------------------+

/ | \
Да | Нет
v | v

`# Преобразование в оттенки серого`

`gray = cv2.cvtColor(frame, cv2.COLOR_BGR2GRAY)`

`# Обработка изображения`

cap.release()

cv2.destroyAllWindows()

### Результаты и тестирование

На этапе тестирования система успешно обнаруживала препятствия на пути дрона. При тестах были настроены сценарии уклонения, а также автономной посадки в случаях, когда столкновение было неизбежно. Реакция на препятствия была достаточно быстрой для предотвращения серьезных инцидентов.

### Заключение

Разработанная система успешно решает задачу по предотвращению столкновений дрона с препятствиями. С помощью камеры и алгоритмов компьютерного зрения Raspberry Pi может обнаруживать потенциальные угрозы и корректно реагировать на них. В будущем можно улучшить систему за счет использования более продвинутых методов машинного обучения для точного распознавания объектов и повышения скорости реакции системы.

`# Здесь можно вставить алгоритмы выделения контуров или детекции объектов

(YOLO/SSD)`

`# Отображение кадра`

`cv2.imshow('Frame', gray)`

`# Выход при нажатии 'q'`

`if cv2.waitKey(1) & 0xFF == ord('q'):`

`break`

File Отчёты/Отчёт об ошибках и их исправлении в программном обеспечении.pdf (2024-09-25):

# Программное обеспечение №1: Сервер

# Программное обеспечение №2: Мобильное приложение

# Программное обеспечение №3: Система управления дроном типа Tailsitter

1. Выявлена проблема в изменении архитектуры вставки самоподписанных

сертификатов о безопасности соединения. Решением было перевести архитектуру

проекта на протокол http в рамках прототипа. Для масштабирования были

использованы сертификаты безопасности соединения с закрытым ключом и переводом

протокола соединения на https

2. Выявлена проблема в использовании сервером на ASP.NET неоткрытых портов для

IP4. Решением было проработка сетевой архитектуры серверной машины и

необходимая сетевая работа

1. Отсутствие работоспособных бесплатных версий API для использования

нативных карт в рамках прототипа. Решением было перейти на условную

архитектуру с введёным модулем дополнительного оператора, который будет

сообщать оператору дрона точные координаты запрошенного местоположения.

Команда находится в активном поиске решений c бесплатными API.

2. Xamarin C# Visual Studio имеет недоработку в линковщике проекта для

создания .dll созданного приложения. Решением было подключение дополнительных

зависимостей в .csproj проекта

3. Выявление и решение проблемы с тонкостями сетевого взаимодействия в

локальной сети между клиенсткой частью и серверной

1. Выявление неверных параметров в готовых open-source решениях в плане

математической реализации. Решением было точных рассчёт аэродинамических

характеристик нашего прототипа и исправления математики в связи с ними

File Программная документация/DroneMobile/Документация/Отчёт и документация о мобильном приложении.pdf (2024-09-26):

### Общее описание

Приложение является мобильным клиентом, разработанным на платформе Xamarin с использованием языка C#. Оно предназначено для управления дронами и взаимодействия с сервером для передачи и получения данных о дронах. Пользователь вводит координаты, отправляет их на сервер, а также может просматривать и изменять статус дронов.

### Основные функции приложения:

### Описание основных страниц

### 1. Главная страница

На главной странице пользователю предоставляется возможность ввести координаты и отправить их на сервер.

Основные элементы интерфейса:

### Логика работы:

1. Отправка координат на сервер: Пользователь вводит координаты и отправляет их на сервер для дальнейшего использования.
2. Просмотр списка дронов: Приложение отображает информацию о всех дронах, находящихся в базе данных на сервере.
3. Изменение статусов дронов: Пользователь может изменять статус дронов и отправлять обновленные данные обратно на сервер.

Поле для ввода широты.
Поле для ввода долготы.
Кнопка отправки данных на сервер.
Кнопка для перехода на следующую страницу.

Пользователь вводит координаты (широта и долгота) в соответствующие поля. После ввода данных пользователь нажимает кнопку «Отправить», и данные отправляются на сервер с помощью HTTP-запроса.

### 2. Страница управления дронами

На второй странице пользователь может просматривать информацию о дронах и управлять их статусами.

Основные элементы интерфейса:

### Логика работы:

### Технические аспекты

### 1. Технологии

### 2. Взаимодействие с сервером

### 3. База данных

Таблица/список всех дронов с информацией о каждом (например, ID, текущее состояние).
Поле для изменения состояния конкретного дрона.
Кнопка для отправки изменённых данных на сервер.

При загрузке страницы приложение отправляет запрос к серверу для получения актуальной информации о дронах.
Данные отображаются в виде таблицы или списка с возможностью редактирования статусов.
Пользователь может выбрать дрон и изменить его статус, а затем отправить обновлённые данные на сервер, нажав соответствующую кнопку.

Xamarin.Forms: используется для разработки кроссплатформенного интерфейса. C#: основной язык программирования.
HTTP: используется для связи приложения с сервером (например, с использованием HttpClient для отправки и получения данных).
SQL: база данных на сервере используется для хранения информации о дронах.

Приложение отправляет данные (координаты, измененные статусы дронов) на сервер с использованием POST-запросов.
Сервер, в свою очередь, возвращает информацию о дронах с помощью GET-запросов.

Серверная база данных хранит информацию о дронах: их ID, текущие координаты, состояние и другие возможные параметры. Все данные извлекаются и обновляются с помощью SQL-запросов.

### Возможные улучшения

### Заключение

Приложение является важным инструментом для управления дронами, позволяя пользователям вводить координаты и изменять статус дронов через удобный интерфейс на мобильном устройстве. Интеграция с сервером и базой данных обеспечивает актуальность информации и возможность быстрого обновления данных.

Добавление валидации данных: Например, проверка корректности введённых координат.
Реализация уведомлений: Уведомления о статусе отправки данных на сервер (успешно/ошибка).
Оптимизация работы с базой данных: Обеспечение более быстрого доступа и обновления данных с учётом увеличения объёма информации о дронах.

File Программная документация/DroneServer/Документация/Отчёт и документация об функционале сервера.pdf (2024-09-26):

### Общее описание

Сервер на C# ASP.NET отвечает за приём данных от мобильного приложения, преобразование этих данных в формат миссий для QGroundControl, а также за взаимодействие с базой данных, которая хранит состояние дронов. Сервер выполняет ключевую роль в управлении данными о дронах и координации полетов.

### Основные функции сервера:

### Основные компоненты

### 1. Приём и обработка координат

Сервер принимает координаты через HTTP-запросы от мобильного приложения и преобразует их в нужный формат для QGroundControl.

### Этапы обработки:

### 2. Интеграция с QGroundControl

1. Приём координат от мобильного приложения: Сервер получает координаты, отправленные с мобильного устройства, и преобразует их в файл формата .plane , который используется для создания миссий в QGroundControl.
2. Интеграция с QGroundControl: После обработки координат сервер сохраняет сгенерированный файл миссии в папку missions для последующей загрузки в QGroundControl.
3. Взаимодействие с базой данных: Сервер хранит и обрабатывает информацию о состоянии дронов по их ID, отправляет данные в мобильное приложение и обрабатывает изменения, поступающие с него.
1. Сервер получает координаты в виде широты и долготы через POST-запрос от мобильного приложения.
2. Эти данные преобразуются в файл формата .plane . В этом файле содержится информация о миссии для QGroundControl, включая координаты точки для полёта.
3. Сгенерированный файл сохраняется в специальную папку missions на сервере, откуда его можно загрузить в QGroundControl для планирования миссии.

QGroundControl использует файлы формата .plane для создания и управления миссиями дронов. Сервер автоматически генерирует такие файлы на основе входных данных, предоставляемых мобильным приложением. Пользователи могут вручную загрузить эти миссии через интерфейс QGroundControl для выполнения полетов.

### 3. Работа с базой данных

Сервер взаимодействует с базой данных, которая хранит состояние дронов (например, "в полёте", "зарядка" и т.д.). Каждый дрон имеет уникальный идентификатор (ID), привязанный к его состоянию.

### Основные операции с базой данных:

### Технические аспекты

### 1. Технологии

1. Чтение данных:
Сервер отправляет информацию о всех дронах в мобильное приложение, включая их ID и текущее состояние.
Эти данные предоставляются через GET-запрос, который выполняется при каждом запросе со стороны приложения.
2. Обновление данных:
Мобильное приложение может отправить обновленные данные о состоянии конкретного дрона.
Сервер обрабатывает эти изменения и вносит их в базу данных с помощью SQL-запросов, обновляя состояние дронов в соответствии с новыми данными.

ASP.NET Core: используется для разработки серверной части, поддерживающей работу с API и взаимодействие с базой данных.
Entity Framework: применяется для работы с базой данных.
SQL Server или другой реляционный DBMS: хранение информации о дронах и их состояниях.
HTTP API: взаимодействие с мобильным приложением осуществляется через HTTP-запросы (POST и GET).
QGroundControl: программное обеспечение для управления миссиями дронов, использующее файлы .plane .

### 2. Взаимодействие с мобильным приложением

### 3. Пример структуры данных

### 4. Преобразование в формат .plane

Пример процесса преобразования:

### Возможные улучшения

### Заключение

Сервер на C# ASP.NET выполняет ключевые задачи по приёму координат, их преобразованию для QGroundControl, а также по управлению данными о дронах и их

POST-запросы: используются для отправки координат и обновлений состояния дронов.
GET-запросы: используются для получения данных о текущем состоянии дронов. Все запросы обрабатываются сервером с помощью контроллеров API, что обеспечивает гибкость и масштабируемость системы.

Дроны:
ID : уникальный идентификатор дрона.
Статус : текущее состояние дрона (в полёте, на зарядке и т.д.).
Другие параметры, такие как текущие координаты или последние задания.

Полученные координаты обрабатываются в формате JSON/XML.
Создаётся файл .plane , содержащий информацию о точке полёта, которая будет интерпретирована QGroundControl как цель миссии.
Файл сохраняется в папку missions , откуда его можно загрузить в QGroundControl.

Автоматическая загрузка миссий: Настроить автоматическую загрузку сгенерированных файлов миссий в QGroundControl без необходимости ручной загрузки.
Добавление валидации данных: Проверка корректности введённых координат и статусов дронов для предотвращения ошибок.
Оптимизация работы с базой данных: Внедрение механизмов кеширования для ускорения операций чтения данных о дронах.

состояниях в базе данных. Система обеспечивает связь между мобильным приложением, QGroundControl и базой данных, что делает процесс управления дронами удобным и эффективным.

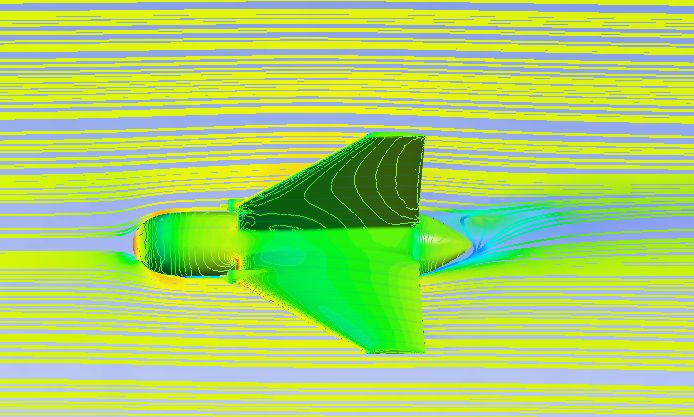
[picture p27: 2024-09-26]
Результаты расчета/Ansys/Альфа_0_1.png

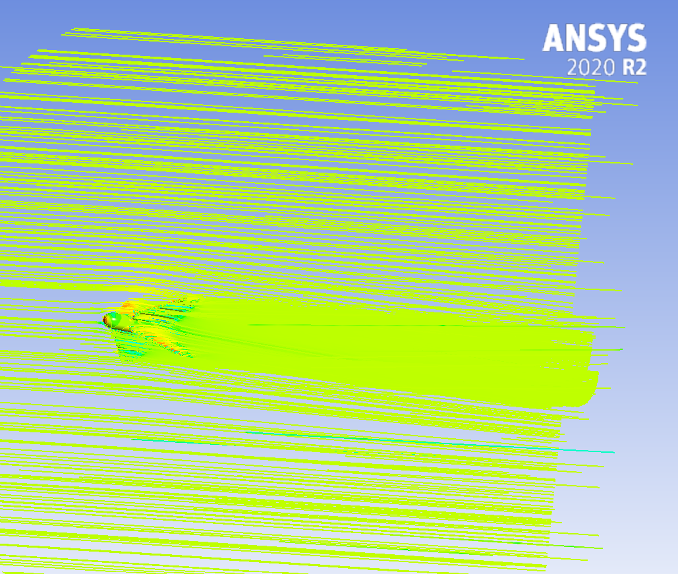
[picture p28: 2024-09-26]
Результаты расчета/Ansys/Альфа_6_1.png

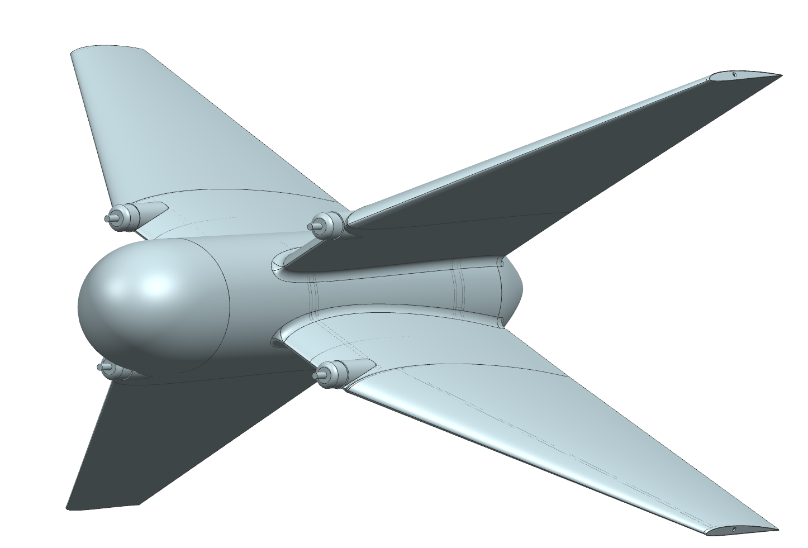
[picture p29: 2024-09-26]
Моделирование/Скриншоты модели/Общий вид изделия.png

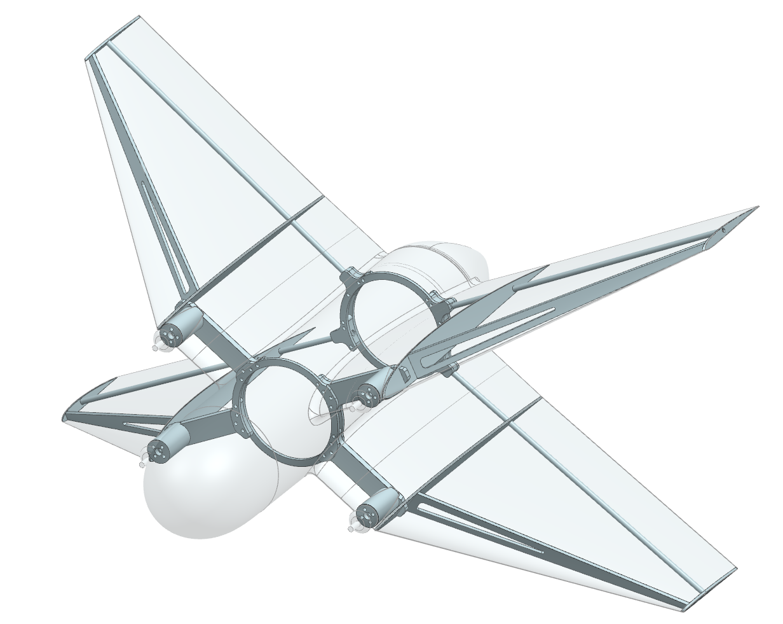
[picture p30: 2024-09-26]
Моделирование/Скриншоты модели/КСС в сборе.png

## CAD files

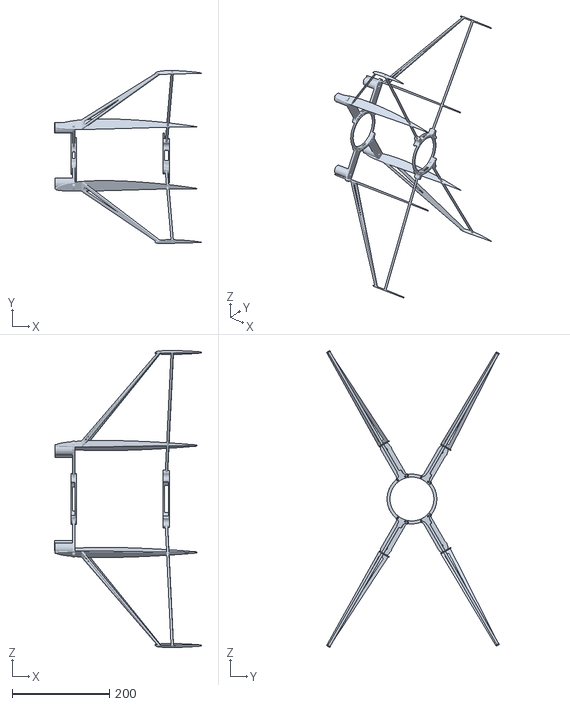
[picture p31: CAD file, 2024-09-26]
Моделирование/STL/КСС.stl
301.8 x 354.9 x 609.4

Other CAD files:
Моделирование/centrovka and wing.dwg
Прототипирование/нервюра концевая.dwg
Прототипирование/нервюра корневая.dwg
Моделирование/3d model in prt (NX format)/Sagittarius.prt
Моделирование/3d model in prt (NX format)/Wing_top.prt
Моделирование/3d model in prt (NX format)/БРЭО.prt
Моделирование/3d model in prt (NX format)/КСС.prt
Моделирование/3d model in prt (NX format)/Теорконтур.prt
Прототипирование/обтекатели.x_t

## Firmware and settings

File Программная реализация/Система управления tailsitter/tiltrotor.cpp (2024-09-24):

/**

@file tiltrotor.cpp
@brief Tiltrotor VTOL type implementation.
This file contains the control logic for a tiltrotor VTOL aircraft, which transitions between multicopter
mode and fixed-wing mode by tilting its rotors. The transitions are controlled by various parameters
and conditions such as speed, time, and tilt angle. */

#include "tiltrotor.h"
#include "vtol_att_control_main.h"

using namespace matrix;

#define FRONTTRANS_THR_MIN 0.25f
#define BACKTRANS_THROTTLE_DOWNRAMP_DUR_S 0.5f
#define BACKTRANS_THROTTLE_UPRAMP_DUR_S 0.5f

/**

@brief Constructor for the Tiltrotor class.
Initializes the tiltrotor control system by calling the base class constructor.
@param attc Pointer to VtolAttitudeControl object. */

Tiltrotor::Tiltrotor(VtolAttitudeControl *attc) :
	VtolType(attc)
{
}

/**

@brief Updates the tiltrotor parameters.
Updates the VTOL parameters from the parameter store. */

void
Tiltrotor::parameters_update()
{
	VtolType::updateParams();
}

/**

@brief Updates the VTOL state.

Controls the state transitions between multicopter (MC) and fixed-wing (FW) modes,

based on conditions such as user input, speed, and tilt angles. It also handles

failsafe events that force immediate transitions. */

void Tiltrotor::update_vtol_state()
{
	/* simple logic using a two way switch to perform transitions.
	 * after flipping the switch the vehicle will start tilting rotors, picking up
	 * forward speed. After the vehicle has picked up enough speed the rotors are tilted
	 * forward completely. For the backtransition the motors simply rotate back.
	*/

	if (_vtol_vehicle_status->fixed_wing_system_failure) {
		// Failsafe event, switch to MC mode immediately
		_vtol_mode = vtol_mode::MC_MODE;

	} else 	if (!_attc->is_fixed_wing_requested()) {

		// plane is in multicopter mode
		switch (_vtol_mode) {
		case vtol_mode::MC_MODE:
			break;

		case vtol_mode::FW_MODE:
			resetTransitionStates();
			_vtol_mode = vtol_mode::TRANSITION_BACK;
			break;

		case vtol_mode::TRANSITION_FRONT_P1:
			// failsafe into multicopter mode
			_vtol_mode = vtol_mode::MC_MODE;
			break;

		case vtol_mode::TRANSITION_FRONT_P2:
			// failsafe into multicopter mode
			_vtol_mode = vtol_mode::MC_MODE;
			break;

		case vtol_mode::TRANSITION_BACK:
			const bool exit_backtransition_tilt_condition = _tilt_control <= (_param_vt_tilt_mc.get() + 0.01f);

			// speed exit condition: use ground if valid, otherwise airspeed
			bool exit_backtransition_speed_condition = false;

			if (_local_pos->v_xy_valid) {
				const Dcmf R_to_body(Quatf(_v_att->q).inversed());
				const Vector3f vel = R_to_body * Vector3f(_local_pos->vx, _local_pos->vy, _local_pos->vz);
				exit_backtransition_speed_condition = vel(0) < _param_mpc_xy_cruise.get() ;

			} else if (PX4_ISFINITE(_airspeed_validated->calibrated_airspeed_m_s)) {
				exit_backtransition_speed_condition = _airspeed_validated->calibrated_airspeed_m_s < _param_mpc_xy_cruise.get() ;
			}

			const bool exit_backtransition_time_condition = _time_since_trans_start > _param_vt_b_trans_dur.get() ;

			if (exit_backtransition_tilt_condition && (exit_backtransition_speed_condition || exit_backtransition_time_condition)) {
				_vtol_mode = vtol_mode::MC_MODE;
			}

			break;
		}

	} else {

		switch (_vtol_mode) {
		case vtol_mode::MC_MODE:
			// initialise a front transition
			resetTransitionStates();
			_vtol_mode = vtol_mode::TRANSITION_FRONT_P1;
			break;

		case vtol_mode::FW_MODE:
			break;

		case vtol_mode::TRANSITION_FRONT_P1: {
				if (isFrontTransitionCompleted()) {
					_vtol_mode = vtol_mode::TRANSITION_FRONT_P2;
					_trans_finished_ts = hrt_absolute_time();
					resetTransitionStates();
				}

				break;
			}

		case vtol_mode::TRANSITION_FRONT_P2:

			// if the rotors have been tilted completely we switch to fw mode
			if (_tilt_control >= _param_vt_tilt_fw.get()) {
				_vtol_mode = vtol_mode::FW_MODE;
				_tilt_control = _param_vt_tilt_fw.get();
			}

			break;

		case vtol_mode::TRANSITION_BACK:
			// failsafe into fixed wing mode
			_vtol_mode = vtol_mode::FW_MODE;
			break;
		}
	}

	// map tiltrotor specific control phases to simple control modes
	switch (_vtol_mode) {
	case vtol_mode::MC_MODE:
		_common_vtol_mode = mode::ROTARY_WING;
		break;

	case vtol_mode::FW_MODE:
		_common_vtol_mode = mode::FIXED_WING;
		break;

	case vtol_mode::TRANSITION_FRONT_P1:
	case vtol_mode::TRANSITION_FRONT_P2:
		_common_vtol_mode = mode::TRANSITION_TO_FW;
		break;

	case vtol_mode::TRANSITION_BACK:
		_common_vtol_mode = mode::TRANSITION_TO_MC;
		break;
	}
}

/**

@brief Updates the multicopter state.

Adjusts the control values specific to multicopter mode, such as yaw control and tilt angle. */

void Tiltrotor::update_mc_state()
{
	VtolType::update_mc_state();

	_tilt_control = VtolType::pusher_assist() + _param_vt_tilt_mc.get();
	_mc_yaw_weight = 1.0f;
}

/**

@brief Updates the fixed-wing state.

Adjusts the control values specific to fixed-wing mode, such as throttle and tilt angle. */

void Tiltrotor::update_fw_state()
{
	VtolType::update_fw_state();

	// this is needed to avoid a race condition when entering backtransition when the mc rate controller publishes
	// a zero throttle value
	_v_att_sp->thrust_body[2] = -_v_att_sp->thrust_body[0];

	// make sure motors are tilted forward
	_tilt_control = _param_vt_tilt_fw.get();
}

/**

@brief Updates the transition state between MC and FW modes.

Controls the transition process, including tilt angles, thrust adjustments, and blending of control weights. */
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

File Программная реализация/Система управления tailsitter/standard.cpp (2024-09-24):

/**
 * @file standard.cpp
 * @brief Implementation of the Standard VTOL (Vertical Takeoff and Landing) attitude control.
 */

#include "standard.h"
#include "vtol_att_control_main.h"

#include <float.h>

using namespace matrix; 

/**
 * @brief Constructor for the Standard class.
 * @param attc Pointer to the VTOL attitude control object.
 */

Standard::Standard(VtolAttitudeControl *attc) :
	VtolType(attc)
{
}

/**
 * @brief Updates the parameters for the VTOL control system.
 */

void
Standard::parameters_update()
{
	VtolType::updateParams();

	// make sure that pusher ramp in backtransition is smaller than back transition (max) duration
	_param_vt_b_trans_ramp.set(math::min(_param_vt_b_trans_ramp.get(), _param_vt_b_trans_dur.get()));
}

/**
 * @brief Updates the current VTOL state, which includes managing the transition between
 * multicopter and fixed-wing modes, handling motor state changes, and engaging failsafe modes.
 */

void Standard::update_vtol_state()
{
    /* After switching to FW mode, the vehicle will start the pusher motor, picking up
	     * forward speed. After reaching enough speed, the rotors shut down.
	     * In backtransition, the pusher motor stops immediately, and rotors reactivate.
	     */

	float mc_weight = _mc_roll_weight;

	if (_vtol_vehicle_status->fixed_wing_system_failure) {
		// Failsafe event, engage mc motors immediately
		_vtol_mode = vtol_mode::MC_MODE;
		_pusher_throttle = 0.0f;

	} else if (!_attc->is_fixed_wing_requested()) {

		// the transition to fw mode switch is off
		if (_vtol_mode == vtol_mode::MC_MODE) {
			// in mc mode
			_vtol_mode = vtol_mode::MC_MODE;
			mc_weight = 1.0f;

		} else if (_vtol_mode == vtol_mode::FW_MODE) {
			// Regular backtransition
			resetTransitionStates();
			_vtol_mode = vtol_mode::TRANSITION_TO_MC;

		} else if (_vtol_mode == vtol_mode::TRANSITION_TO_FW) {
			// failsafe back to mc mode
			_vtol_mode = vtol_mode::MC_MODE;
			mc_weight = 1.0f;
			_pusher_throttle = 0.0f;

		} else if (_vtol_mode == vtol_mode::TRANSITION_TO_MC) {
			// speed exit condition: use ground if valid, otherwise airspeed
			bool exit_backtransition_speed_condition = false;

			if (_local_pos->v_xy_valid) {
				const Dcmf R_to_body(Quatf(_v_att->q).inversed());
				const Vector3f vel = R_to_body * Vector3f(_local_pos->vx, _local_pos->vy, _local_pos->vz);
				exit_backtransition_speed_condition = vel(0) < _param_mpc_xy_cruise.get();

			} else if (PX4_ISFINITE(_airspeed_validated->calibrated_airspeed_m_s)) {
				exit_backtransition_speed_condition = _airspeed_validated->calibrated_airspeed_m_s < _param_mpc_xy_cruise.get();
			}

			const bool exit_backtransition_time_condition = _time_since_trans_start > _param_vt_b_trans_dur.get();

			if (can_transition_on_ground() || exit_backtransition_speed_condition || exit_backtransition_time_condition) {
				_vtol_mode = vtol_mode::MC_MODE;
			}
		}

	} else {
		// the transition to fw mode switch is on
		if (_vtol_mode == vtol_mode::MC_MODE || _vtol_mode == vtol_mode::TRANSITION_TO_MC) {
			// start transition to fw mode
			/* NOTE: The failsafe transition to fixed-wing was removed because it can result in an
			 * unsafe flying state. */
			resetTransitionStates();
			_vtol_mode = vtol_mode::TRANSITION_TO_FW;

		} else if (_vtol_mode == vtol_mode::FW_MODE) {
			// in fw mode
			_vtol_mode = vtol_mode::FW_MODE;
			mc_weight = 0.0f;

		} else if (_vtol_mode == vtol_mode::TRANSITION_TO_FW) {

			if (isFrontTransitionCompleted()) {
				_vtol_mode = vtol_mode::FW_MODE;

				// don't set pusher throttle here as it's being ramped up elsewhere
				_trans_finished_ts = hrt_absolute_time();
			}
		}
	}

	_mc_roll_weight = mc_weight;
	_mc_pitch_weight = mc_weight;
	_mc_yaw_weight = mc_weight;
	_mc_throttle_weight = mc_weight;

	// map specific control phases to simple control modes
	switch (_vtol_mode) {
	case vtol_mode::MC_MODE:
		_common_vtol_mode = mode::ROTARY_WING;
		break;

	case vtol_mode::FW_MODE:
		_common_vtol_mode = mode::FIXED_WING;
		break;

	case vtol_mode::TRANSITION_TO_FW:
		_common_vtol_mode = mode::TRANSITION_TO_FW;
		break;

	case vtol_mode::TRANSITION_TO_MC:
		_common_vtol_mode = mode::TRANSITION_TO_MC;
		break;
	}
}

/**
 * @brief Updates the state during transitions between multicopter and fixed-wing modes.
 */

void Standard::update_transition_state()
{
	const hrt_abstime now = hrt_absolute_time();
	float mc_weight = 1.0f;

	VtolType::update_transition_state();

	const Eulerf attitude_setpoint_euler(Quatf(_v_att_sp->q_d));
	float roll_body = attitude_setpoint_euler.phi();
	float pitch_body = attitude_setpoint_euler.theta();
	float yaw_body = attitude_setpoint_euler.psi();

	// we get attitude setpoint from a multirotor flighttask if climbrate is controlled.
	// in any other case the fixed wing attitude controller publishes attitude setpoint from manual stick input.
	if (_v_control_mode->flag_control_climb_rate_enabled) {
		// we need the incoming (virtual) attitude setpoints (both mc and fw) to be recent, otherwise return (means the previous setpoint stays active)
		if (_mc_virtual_att_sp->timestamp < (now - 1_s) || _fw_virtual_att_sp->timestamp < (now - 1_s)) {
			return;
		}

		memcpy(_v_att_sp, _mc_virtual_att_sp, sizeof(vehicle_attitude_setpoint_s));
		roll_body = Eulerf(Quatf(_fw_virtual_att_sp->q_d)).phi();

	} else {
		// we need a recent incoming (fw virtual) attitude setpoint, otherwise return (means the previous setpoint stays active)
		if (_fw_virtual_att_sp->timestamp < (now - 1_s)) {
			return;
		}

		memcpy(_v_att_sp, _fw_virtual_att_sp, sizeof(vehicle_attitude_setpoint_s));
		_v_att_sp->thrust_body[2] = -_fw_virtual_att_sp->thrust_body[0];
	}

	if (_vtol_mode == vtol_mode::TRANSITION_TO_FW) {
		if (_param_vt_psher_slew.get() <= FLT_EPSILON) {
			// just set the final target throttle value
			_pusher_throttle = _param_vt_f_trans_thr.get();

		} else if (_pusher_throttle <= _param_vt_f_trans_thr.get()) {
			// ramp up throttle to the target throttle value
			const float dt = math::min((now - _last_time_pusher_transition_update) / 1e6f, 0.05f);
			_pusher_throttle = math::min(_pusher_throttle +
						     _param_vt_psher_slew.get() * dt, _param_vt_f_trans_thr.get());

			_last_time_pusher_transition_update = now;
		}

		_airspeed_trans_blend_margin = getTransitionAirspeed() - getBlendAirspeed();

		// do blending of mc and fw controls if a blending airspeed has been provided and the minimum transition time has passed
		if (_airspeed_trans_blend_margin > 0.0f &&
		    PX4_ISFINITE(_airspeed_validated->calibrated_airspeed_m_s) &&
		    _airspeed_validated->calibrated_airspeed_m_s > 0.0f &&
		    _airspeed_validated->calibrated_airspeed_m_s >= getBlendAirspeed() &&
		    _time_since_trans_start > getMinimumFrontTransitionTime()) {

			mc_weight = 1.0f - fabsf(_airspeed_validated->calibrated_airspeed_m_s - getBlendAirspeed()) /
				    _airspeed_trans_blend_margin;
			// time based blending when no airspeed sensor is set
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

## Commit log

2024-09-23 Модуль А
    Выполнение модуля А
2024-09-24 Модуль Б(Обновление README файла)
    Обновление README файла
2024-09-24 Модуль Б(Догрузка файлов)
    Догрузка файлов
    [Sagittarius model.stl]
2024-09-25 Rename Sagittarius model.stl to models/Sagittariusmodel.stl
    [Sagittariusmodel.stl]
2024-09-25 Структуризация гит проекта
    [Sagittarius model.x_t]
2024-09-25 Структуризация git проекта
2024-09-26 Актуальные модели в формате step
2024-09-26 Актуальные модели в формате STL
    [КСС.stl]
2024-09-26 Скриншоты модели
2024-09-26 Результаты летных испытаний
2024-09-26 Центровочная схема и геом-ие параметры крыла
    [centrovka and wing.dwg]
2024-09-26 Результаты расчета
2024-09-26 Итоговый отчет
2024-09-26 PDF версия отчёта
2024-09-26 Финальный отчёт в формате PDF
2024-09-26 Расчет аэродинамических характеристик
    [Аэродинамика.xlsx]
2024-09-26 Rename финальный отчёт .pdf to Итоговый отчёт .pdf
